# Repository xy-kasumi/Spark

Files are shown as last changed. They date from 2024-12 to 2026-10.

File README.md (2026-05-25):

# Spark

🚧 Under Construction 🚧

Spark is an OSS/OSH desktop EDM tech stack.
It'll bring the ease of 3D printing to fine metal parts.

Maybe. Someday.

This repo is mostly about software & machine CAD.

To construct a Spark machine, you need these too:
* https://github.com/xy-kasumi/Spark-corefw
  * firmware for main board (currently only supports BTT Octopus Pro)
* https://github.com/xy-kasumi/Spark-pulser
  * EDM board (PCB design & firmware)

## Directories

Directories are roughly divided into two groups.

### Build & Use

* docs: contains assembly manuals and specs
* dicer: web page that generates G-code from STL for the machine
* shell-dashboard: web page to control the machine
* shell-spooler: Go program that acts as interface between shell-dashboard & physical board
* mech: CAD files for the machine

These are necessary for building, testing, and using the machine.

### Development & Operations

* sim-wear: particle-based tool vs work simulation
  * purpose: validate & iterate on "sweep" patterns without physical experiments
* brand: contains project's visual identity such as logo

These are useful resources to further the development of the machine and/or the Spark project.

### Tips
Note: "localhost" and "127.0.0.1" are considered different origins.

When `./build.sh` or `./watch.sh` cause directory listing page to show up:
* Configure `liveServer.settings.wait` to be larger than build time. e.g. 1500 (ms)

When log output from spooler is causing refresh:
* Add `"**/logs/**"` to `liveServer.settings.ignoreFiles`.

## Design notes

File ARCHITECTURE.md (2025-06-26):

From the user's point of view, Spark stack looks like this:

```mermaid
graph LR
    Dicer --G-code--> Shell
    subgraph Machine
      Shell <--command stream--> Core
    end
```

* Dicer is a GUI that user puts 3D file & configs, and emits G-code
* Machine receives G-code via Shell, and carves out 3D physical object
  * Core is the firmware that abstracts hardware as [a serial protocol](https://github.com/xy-kasumi/Spark-corefw/blob/main/spec/protocol.md)

Machine's UI can vary:
* it can be hardware display, knobs etc
* it can be web UI

## Why not X?

### Why not Klipper?
In Klipper, Linux board runs Python to generate low-level (individual motor steps) with timestamps, and stream them to firmwares.
* Firmwares buffers low-level commands and executes them based on timestamps.

Issues
* Low-level timestamped commands (core design chocie in Klipper) will not work in EDM
  * EDM control loop needs fast (probably 100Hz+) realtime control based on sensing.
  * Python + Linux is not well-suited to handle such low-latency computation reliably for hours.
  * Monotonic timestamp is also very-baked in idea, canceling and re-ordering of commands look hard.

Good things
* Separation of UI & control

### Why not grblHAL?
grblHAL is a pretty flexible firmware for generic CNC machine.
It also provides HAL (hardware abstraction layer) for electronics, plugin-based flexible architecture.

Issues
* Too hard to change behavior of G1 for EDM-control loop
  * Lots of non-plugin exposed behavior (need to modify core code)
  * G-code & motion planning ring buffers is too baked in for a change to backtrackable data structure
* Sender GUIs assumes too much machine knoweldge from users
  * We won't be using them anyway

### Why not Marlin?
Marlin is basically everything-in-single-firmware design.

Issues
* Since machine geometry & UI will be quite different, very little can be reused from Marlin firmware.
  * Rewrite would be easier.

## Spark Architecture
Assumption is that:
* Core is very minimum; zero user I/O, no SD-card. Only command stream over UART.
* Linux single board computer (e.g. Raspberry Pi) handles every UI

Spooler provides non-realtime machine interface by:
* keep G-code cache locally
* streams G-code reliably & monitors Core even when network is offline or dashboard is gone
* spooler's knowledge of the protocol or G-code is minimum; it's basically a HTTP-accessible line-based storage

The command stream is high-level (G-code + system commands).
Core buffers hopefully more than 1 second of G-code,
to prevent occasional hiccups in Linux from causing troubles.

Final setup of Split Shell
```mermaid
graph LR
  subgraph Host
    Dashboard["Dashboard in browser"]
  end
  subgraph Machine
    subgraph Single Board Computer
      Server["HTTP Server"]
      Static["Dashboard Static Files"]
      Spooler
      Server--reads-->Static
      Server--proxies-->Spooler
      PhysUI["Physical UI"] -->Spooler
    end
    subgraph Electronics
      Core["Core Firmware"]
    end
    Spooler<--command stream-->Core
  end
  Dashboard--->Server
```

By having "Physical UI" program which interfaces with buttons, displays, speakers etc,
it's very easy to have on-device rich UI if wanted.

Split shell configuration allows same dashboard & spooler to be used in host environment,
offering rich & flexible dashboard while developing hardware & electronics.
```mermaid
graph LR
  subgraph Host
    Dashboard --> Spooler
  end
  subgraph Machine
    subgraph Electronics
      Core["Core Firmware"]
    end
  end
  Spooler<--command stream-->Core
```

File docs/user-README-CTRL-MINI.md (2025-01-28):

# CTRL-MINI (r0) User Manual

This doc is for users of the CTRL-MINI board.
It serves as both a datasheet and an operating manual.

## Overview

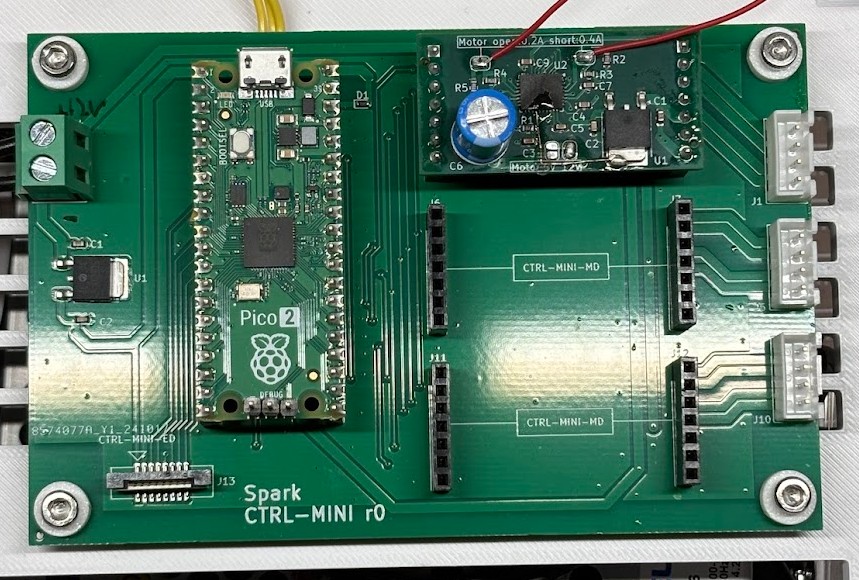
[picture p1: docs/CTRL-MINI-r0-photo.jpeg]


CTRL-MINI is the main board of a Spark machine.
In the current prototype phase, it serves as an experimental hub.
Major revisions are expected in future iterations.

It features the following functionality:
- Terminal-like interface for human operator via RasPi probe
- 3-axis bipolar stepper motor driver with swappable child boards (CTRL-MINI-MD)
  - 12V, 0.4-ish A per phase
  - Features Trinamic TMC2130 driver with 1/256 microstepping capability
- Connectivity to CTRL-MINI-ED board

Note: The architectural relationship between CTRL-MINI and CTRL-MINI-ED (whether as a sub-component or separate board) is TBD. This document treats it as a separate board.

### Power Supply

Screw terminal on the left side:
- Input: 12VDC
- Current: 2A minimum recommended
  - 1A minimum if using reduced motor current
  - Higher current ratings are OK

### Connections

Right edge: Motors
- 3x XH connectors
  - Pin configuration (top to bottom):
    1: A1
    2: A2
    3: B1
    4: B2

Bottom edge: CTRL-MINI-ED connection
- Upright connector for FFC (Flat Flexible Cable)
  - Type-A, pitch 1mm, 8 pins
  - Terminal thickness: 0.3mm

Top edge: RasPi Probe (Serial Communication)
- QI female 3-pin connector
  1: TX
  2: RX
  3: GND

### Mechanical
Reference orientation: "Spark" text on board facing up

**General**
* Outer dimensions: 115mm (width) x 75mm (height) x 25mm (depth)
* Mass: to-be-measured

**Mounting**
Board dimensions: 115mm (width) x 75mm (height)
- 4x mounting holes:
  - Coordinates: (5mm, 5mm), (5mm, 70mm), (110mm, 5mm), (110mm, 70mm)
  - Hole diameter: 3.3mm
  - Clearance for screw head/spacer: 8mm diameter
  - Mounting areas are electrically isolated

## Terminal Interface

Connect the RasPi probe's serial port to the 3-pin QI connector.
Use any terminal emulator software on the host computer.

Required configuration:
- Baud rate: 115200

Recommended configuration:
- Line ending: CR (for both TX/RX)
- Local echo: ON

Interface behavior:
- Commands are single-line only (no multi-line support)
- Input control:
  - `Ctrl-C` or `Ctrl-K`: Cancel current command
  - Other control keys are not supported (backspace, arrows, delete)

### High-Level Commands

#### `status`
* **Description:** Prints the status of the system.

#### `edparam <duration_us> <duty> <current_ma>`
* **Description:** Configures pulse duration, duty factor, current. Will affect `drill` command.
* **Parameters:**
  * `duration_us`: integer, pulse duration in microseconds (range: 5 to 10000)
  * `duty`: integer, max duty ratio in percent (range: 1 to 50)
  * `current_ma`: integer, current in mA (range: 100 to 8000). Will be rounded down to possible value.

#### `move <board_ix> <distance>`
* **Description:** Moves the specified board by a given distance (in millimeters).
* **Parameters:**
  * `board_ix`: 0, 1, or 2
  * `distance`: float (in mm)

#### `find <board_ix> <distance>`
* **Description:** Moves up to a specified distance or until the electrode touches the work.  
  Uses a hot electrode scan and may cause slight damage to the work.
* **Important:** Must be issued after `edon`.
* **Parameters:**
  * `board_ix`: 0, 1, or 2
  * `distance`: float (in mm)

#### `drill <board_ix> <distance>`
* **Description:** Drills by a specified distance. Actual drill depth may be less due to tool wear.
* **Important:** Must be issued after `edon`.
* **Parameters:**
  * `board_ix`: 0, 1, or 2
  * `distance`: float (in mm)

### Motor Driver (MD) Commands

#### `step <board_ix> <step> <wait>`
* **Description:** Steps one motor in one direction at a constant speed.
* **Parameters:**
  * `board_ix`: 0, 1, or 2
  * `step`: integer (negative or positive), in microsteps
  * `wait`: integer, wait time after each microstep, in microseconds

#### `home <board_ix> <direction> <timeout_ms>`
* **Description:** Moves the motor to the home position (where it stalls).
* **Parameters:**
  * `board_ix`: 0, 1, or 2
  * `direction`: `-` or `+`
  * `timeout_ms`: integer, timeout in milliseconds

#### `regread <board_id> <addr>`
* **Description:** Reads a register from peripheral boards.
* **Parameters:**
  * `board_id`: 0, 1, 2, E
  * `addr`: hexadecimal value from `00` to `7f`

### Low-Level Commands

#### `regwrite <board_id> <addr> <data>`
* **Description:** Writes to a register on the peripheral boards.
* **Parameters:**
  * `board_id`: 0, 1, 2, E
  * `addr`: hexadecimal value from `00` to `7f`
  * `data`: hexadecimal, 1-byte for E, 4-byte for 0,1,2
* **Examples:**
  * `regwrite E 02 01`
  * `regwrite 0 10 1f10`

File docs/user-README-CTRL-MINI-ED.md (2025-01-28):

# CTRL-MINI-ED (r1) User Manual

This doc is for users of the CTRL-MINI-ED board.
It basically serves as both a datasheet and an operating manual.

## ⚠️ Safety warning ⚠️
Improper use of CTRL-MINI-ED may cause death, fire, or damage to nearby devices.

## Overview

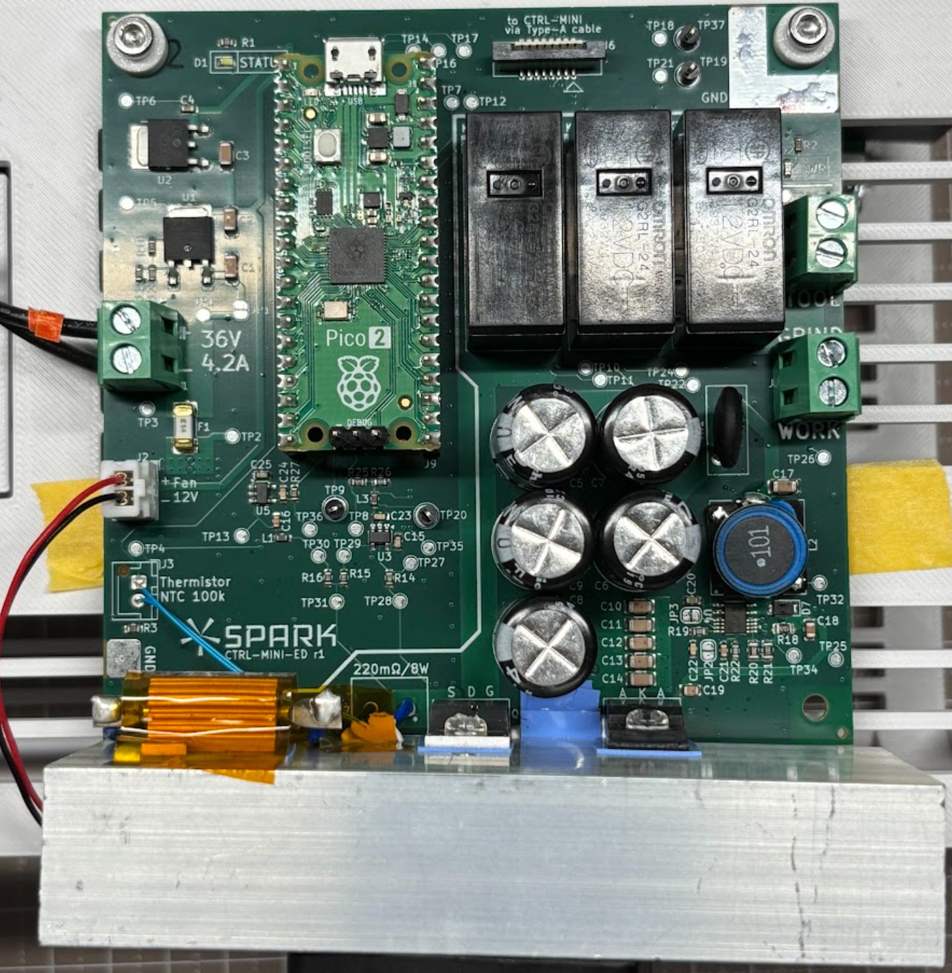
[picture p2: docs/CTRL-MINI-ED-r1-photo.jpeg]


CTRL-MINI-ED is an EDM discharge board, controllable via digital IOs and I2C.

* Max pulse current: 8A (at duty factor=50%)
* Open voltage: 100V
* 5 dynamic polarity configurations
  * (Tool+, Work-), (Tool-, Work+)
  * (Tool+, Grinder-), (Tool-, Grinder+)
  * Disconnected
* Single-pulse discharge timing control, and pulse current detection via GATE/DETECT digital IOs
* Pulse current, detection threshold, polarity control, temperature monitoring via I2C

### Power Supply
Screw terminal on the left side
* DC 36V, 4.2A minimum

If the power supply is below 4.2 A, the microcontroller might reset accidentally at high-power setting.
Above 4.2 A should be fine, but too much output (e.g. 10 A) will increase the damage in case of firmware bug.

### Indicators

* Status (white) LED: ON if OK. Blinks if error. OFF means hardware or firmware failure.
* Power (red) LED: Indicates that electrodes are potentially energized. Blinks if error.

Even after sudden power failure, electrodes should be in high-impedance state if the Power (red) LED is OFF.
When the board enters an error state, the only way to recover is through a power reset.

### Connections

Control Connector:
* Upright connector for FFC (Flat Flexible Cable)
  * Type-A, pitch 1mm, 8 pins, terminal thickness 0.3mm

Electrodes:
* three screw-terminals on the right side ("Wire", "Grind", "Tool" marking on the PCB)

### Mechanical & Thermal
* Listed values are board with heatsink and fan
* "height", "width" etc. is based on "Spark" logo on the board

**General**
* Outer dimensions: 135mm (width) x 105mm (height) x 50mm (depth)
* Mass: 240g

**Mounting**
Board dimensions: 100mm (width) x 100mm (height)
* 4 mounting holes at (5mm, 5mm), (5mm, 95mm), (95mm, 5mm), (95mm, 95mm)
* Hole dia: 3.3mm, dia available for screw head, spacer etc: 6.5mm
  * available area is either isolated or GND

**Thermal**
* Max heat generation: 75W
  * Ensure adequate airflow at the bottom of the PCB for proper fan operation.

## Controller Interface

CTRL-MINI-ED is designed to be safe (de-energized) to be turned on with "Control Connector" disconnected.

### Physical layer
"Control Connector" pinout (at **host-side**. See note.):
1. Don't Connect
2. GND
3. Don't Connect
4. I2C SDA
5. Don't Connect
6. I2C SCL
7. GATE
8. DETECT

Note: Type-A (terminals on same-side) means cross-cable. Thus, pinout at host and ED board is flipped.

* I2C SDA/SCL: 3.3V I/O. Standard Mode (~100kHz). Pulled-up in ED board.
* GATE: 3.3V digital input
* DETECT: 3.3V digital output

### I2C layer

* Device Address: 0x3B
* Speed: Standard Mode (~100kHz clock)

Within the device, there are registers with 1-byte address and 1-byte data.
Write command writes to a single register, Read command read from a single register.

They involve internal pointer. They don't auto-increment.

**Write**
* M: START
* M: Device Addr (7bit; 0x3B) + Write flag (1bit; 0)
* S: ACK
* M: Register Addr (8bit)
* S: ACK
* M: Data (8bit)
* S: ACK
* M: STOP

This also sets the internal pointer to Register Addr.

**Read**
(write pointer)
* M: START
* M: Device Addr (7bit; 0x3B) + Write flag (1bit; 1)
* S: ACK
* M: Register Addr (8bit)
* S: ACK
(read data from pointer)
* M: Repeated START
* M: Device Addr (7bit; 0x3B) + Read flag (1bit; 1)
* S: Data (8bit)
* M: NACK
* M: STOP

(M: master, S: slave)

### Logical layer

### GATE/DETECT
The host can initiate a single pulse by setting GATE to HIGH.
If the discharge condition is good, discharge will happen after a random Tig (ignition time).
Tig is inherently random, but typically ranges from 10μs to 500μs, and becomes shorter if the gap is narrower.

If DETECT becomes HIGH very quickly (within 5μs), it is highly likely that the discharge gap is short-circuited.
In that case, the host should set GATE to LOW immediately.

Generally, GATE can be thought of as directly driving the MOSFET gate. However, for safety and device longevity,
actual driving can be suppressed. See the "Timing wrt. GATE/DETECT" section for details.

DETECT becomes HIGH whenever discharge current is detected.
The host is responsible for monitoring DETECT and setting GATE to LOW after the desired pulse duration time.
The current detection threshold is auto-set to 25% of pulse current by the ED board.

When POLARITY or PULSE_CURRENT is updated, DETECT can become LOW even when actual discharge
current is still flowing.



There is a constraint for combinations of pulse time, pulse current, and duty factor.
See the "Pulse Shaping" section for details.

Safety note: electrodes are **energized even when GATE is LOW**

Setting GATE to LOW merely means turning down the current close to 0.
However, open voltage of 100V is still present on the electrodes,
and the driver will allow more than 10mA current to flow, which is enough to kill you.

To actually turn them off, you need to set POLARITY to OFF.

### Control Registers
|Address| Register | Access | Resets to | Description |
|---|---|---|---|---|
| 0x01  | POLARITY | RW | 0 | 0: OFF, 1~4: energize with certain polarity. |
| 0x02  | PULSE_CURRENT | RW | 10 | pulse current in 100mA step. 1 (100mA) ~ 80 (8A) is allowed. |
| 0x03  | TEMPERATURE | R | N/A | current heatsink temperature in ℃. 80 means 80℃. 255 means temp reading is unavailable due to severe issue. |

Register access:
* RW: read-write
* R: read-only

Invalid value writes are:
* set to safe default such as OFF (e.g. POLARITY)
* set to nearest valid value (e.g. PULSE_CURRENT)
* ignored for read-only or unused registers (e.g. TEMPERATURE)

#### Timing wrt. GATE/DETECT

Writes to POLARITY & PULSE_CURRENT immediately updates the register.
However, when register is changed during GATE is HIGH,
* change will take effect from the next pulse (once GATE become LOW)
* actual EDM driver will be suppressed for 1ms (PULSE_CURRENT change) and 20ms (POLARITY change)
  * this will lead to very large observed DETECT from the host

As an exception to the delay above, setting POLARITY to OFF immediately shutdown EDM driver.

#### POLARITY

* 0: OFF
* 1: TPWN (Tool+, Work-)
* 2: TNWP (Tool-, Work+)
* 3: TPGN (Tool+, Grinder-)
* 4: TNGP (Tool-, Grinder+)

### Pulse Shaping

Pulse current is limited due to the internal capacitor bank.
* Always: Ip <= 8A (enforced by register)
* When Ip >= 4A: Tp <= 8mC / Ip
  * Tp (max) = 1ms @ Ip = 8A
  * Tp (max) = 1.3ms @ Ip = 6A
* When Ip >= 4A: Ip * DF <= 4A
  * DF (max) = 50% @ Ip = 8A

If DF or pulse duration exceeds these values, discharge current will dwindle to 4A (power supply current) or cause an abrupt voltage drop.

The ED board driver is optimized for EDM. It uses a combination of:
* 100V low-capacity "ignition supply"
* 36V high-capacity "discharge supply"

This is possible because the gap voltage, once ignited, becomes about 20V (up to ~30V, depending on conditions).
This dual supply driver is power-efficient but produces unexpected behavior when connected to non-discharging loads.

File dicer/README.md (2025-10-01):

## Running Dicer
Run `make`. This will generate `dist/`. First-time will be slow, as it will download Emscripten SDK & Manifold libarries.

Serve the `dicer/` or `spark/`. Open `dicer/dist/index.html` in browser.

## Development
Run `make typecheck` to check types correctness w/o touching `dist/`.
Need to run `make` whenver source files are edited.

Run `make clean` to remove built files.

Run `make clean-all` to remove SDKs and libraries too.

### TypeScript Definitions
- `types/qunit.d.ts` - Original QUnit definitions from DefinitelyTyped
- `types/qunit-extensions-v2.d.ts` - Missing QUnit methods from v2
- `types/vendor.d.ts` - Custom .d.ts maintained by us. Aim for max benefit/cost, rather than completeness.

## Internals & Definitions
All coordinate systems are right-handed.

* "setup coordinates"
  * what users see in dicer.
  * Z+ is up. XY-center is stock profile center.
    * stock is always extrusion of a an XY-aligned profile in Z direction.
    * e.g. cylinder (circle in XY extruded in Z), bar (rectangle in XY extruded in Z)
  * Target shape resides in Z+ half-space, "resting" on XY-plane.
* "work coodinates"
  * same as [G55 work coordinate](https://github.com/xy-kasumi/Spark-corefw/blob/main/spec/gcode.md#g55-use-work-coordinate-system)
  * origin is chuck base center
  * stock resides in X- direction
    * profile is mostly YZ-center aligned, but might have offset depending on chuck types

Dicer computes paths in setup coordinates, and then convert them to work coordinates when emitting G-code.

Setup coordinates and work coordinates shares Y+ axis direction.

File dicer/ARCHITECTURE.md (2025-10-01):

# Core Assumptions / Hypotheses
By reading this doc, you'll know how much effort you should use when touching various parts of the code.

This document outlines the foundational truths (axioms), important assumptions, and smaller hypotheses that underpin Dicer.
Each has different implications for how "defensive" or "throwaway" we can be when writing code.

* Axioms: Bedrock truths; if wrong, requires complete rewrite. (30 days)
  * Baked into architecture. No defensive coding needed.
* Assumptions: Important but less absolute; affects ~10% of code. (3 days)
  * Be somewhat defensive - these might change later
* Hypotheses: Small details; affects ~1% of code. (a few hours)
  * Safe to discard or rewrite

Current projection: Dicer needs 30 days to reconstruct from scratch with correct assumptions.
This corresponds to 3K~30K lines of code+doc.

## Axioms
* Dicer converts 3D mesh into G-code
* Dicer provides interactive configuration
* Good G-code generation is the main value of Dicer; thus its logic update will never cease
  * "Good G-code": Aligns with Spark machine's goal (versatile, accurate, robust)
  * -> Path generation logic is continuously running "module" with GUI hooks to allow quick visualization & iteration, instead of test-hardened pure geometry library
* EWR (electrode wear ratio) is bounded, and its value can be user-measurable
  * -> This is the premise of path generation logic. Unbounded EWR means machine needs continuous sensing, completely destroying machine design itself.
* Dicing completes within "non-coffee-break" time to keep interactive configuration meaningful
  * Target: 10 seconds typical, 30 seconds max for complex cases
* Dicer runs on Web browser environment
* Dicer does not depend on external servers

## Assumptions
* Dicer consumes STL file as 3D mesh
* Triangle mesh representation is "better" than other representations (voxel, CSG, NURBS)
  * "better": Amount of effort to achieve correctness is lower while being fast enough

## Hypotheses
* Not documented (cost of separate documentation outweighs cost of re-writing code)
* e.g. SDF should be passed around as serializable Shape object, instead of a function

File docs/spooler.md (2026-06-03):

# Spooler

Spooler manages the [core firmware](https://github.com/xy-kasumi/Spark-corefw/) over serial comm.
It provides
* Command multiplexing & long-running job streaming, via HTTP API
* Text log for later consumption

Spooler's knowledge:
* knows
  * line-based comm (and `; ...` comment stripping)
  * about p-state format
  * queue control (`?queue`, `queue`)
  * cancellation (`!`)
* does not know
  * G-code, Commands (e.g. what "G1", "set", "?pos" means), p-state contents (other than queue)

Terminology
* `up`: comm towards the user (core -> spooler -> UI -> user). `down` is the opposite.
* `init file`: text file that is persisted across reboot, useful for initializing the core. Its lines are queued as commands at the start of each session.
* `session`: a contiguous span during which the device is alive (responding to `?queue`).

## HTTP API

Spooler uses HTTP as RPC.
All API is POST, both request & response are `application/json`.

It sticks to just 3 types of status codes.
* 200 OK: Request is processed succesfully, response is JSON.
* 400 Bad Request: Returned for non-comforming (syntax or semantics) request. Response is human-readable error text.
* 500 Internal Server Error: Request seemed ok, but somehow processing failed. Response is human-readable error text.

### POST /write-line

Send a line.

**Request Schema**

```yaml
properties:
  line: {type: string}
optionalProperties:
  high_prio: {type: bool}
```
* `line`: a valid payload (should not contain newline)
* `high_prio`:
  * if `true`, the payload is sent immediately regardless of job
  * if `false`, it is queued as a command and fails while a job is `WAITING`/`RUNNING`.

**Response Schema**

```yaml
properties:
  ok: {type: bool}
  time: {type: float64}
```
* `ok`: command was enqueued. `false` also indicates the device is currently dead.
* `time`: time of spooler enqueue (timestamp)

**Examples**

Request:
```json
{
  "line": "G1 X10 Y20",
  "high_prio": false
}
```

Response:
```json
{
  "ok": true,
  "time": 1735689600.123
}
```

### POST /get-ps

Get latest p-states of specified tag.

**Request Schema**
```yaml
properties:
  tag: {type: string}
optionalProperties:
  count: {type: int}
```

* `tag`: P-state tag (e.g. "queue", "stat", "init")
* `count`: Max number of p-states to return (must be > 0). 1 if omitted.

**Response Schema**
```yaml
properties:
  pstates:
    elements:
      properties:
        time: {type: number}
        kv: {values: {}}
```

* `pstates`: in latest-first order.
* `time`: timestamp of the p-state reception
* `kv`: flattened representation of p-state (i.e. key can contain ".")

**Example**
Request
```json
{
  "tag": "pos",
  "count": 2
}
```

Response
```json
{
  "pstates": [
    {
      "time": 1735689600,
      "kv": {
        "m.x": 1
      }
    },
    {
      "time": 1735689500,
      "kv": {
        "m.x": 2
      }
    }
  ]
}
```

### POST /status

Get spooler status summary.

**Request Type**

```json
{}
```

**Response Schema**

```yaml
properties:
  time: {type: float64}
  device_alive: {type: bool}
  busy: {type: bool}
  num_pending_commands: {type: int}
optionalProperties:
  running_job: {type: string}
```

* `time`: spooler timestamp of this status
* `device_alive`: true iff the spooler currently believes the device is responsive
  (responding to `?queue`).
* `busy`: some commands are pending to execute (or being executed). High-prio writes do not count as busy.
* `num_pending_commands`: number of commands (either directly or via job)
  * includes commands in core queue
* `running_job`: job_id if a job is running

**Examples**

Request:
```json
{}
```

Response:
```json
{
  "time": 1735689600.123,
  "device_alive": true,
  "busy": true,
  "num_pending_commands": 37
}
```

### POST /cancel

Cancel everything through the stack, including:
* currently running command in core (if device is alive)
* command queue in core (if device is alive)
* command queue in spooler
* waiting / running job in spooler

**Request Type**

```typescript
{}
```

**Response Type**

```typescript
{}
```

### POST /set-init

Set content of init lines. The content will be persisted as a file across spooler reboot.

**Request Type**

```typescript
{
  lines: Array<string>
}
```

**Response Type**

```typescript
{}
```

**Examples**

Request:
```json
{
  "content": ["set cs.g.pos.x 1", "set cs.g.pos.x 2"]
}
```

### POST /get-init

Get current init lines. Empty if not configured or not found.

**Request Type**

```typescript
{}
```

**Response Type**

```typescript
{
  lines: Array<string>
}
```

**Examples**

Request:
```json
{
  "content": ["set cs.g.pos.x 1", "set cs.g.pos.x 2"]
}
```

### POST /add-job

Add a "job", which is a command-list + polls.
Add only succeeds if all existing jobs are ended (`CANCELED` or `COMPLETED`).

Job only starts executing when command queue of both spooler and core become is fully empty.
Job completes when all `commands` are sent and core queue become fully empty.

**Request Schema**
```yaml
properties:
  commands:
    elements: {type: string}
  polls:
    values: {type: float32}
```

* `commands`: list of commands to be executed
* `polls`: list of commands to be periodically sent (interval in sec)

Caller needs to be careful to only send queue-able `commands` and immediate-execute `polls`
to avoid weird execution order or queue overload.

**Response Schema**
```yaml
properties:
  ok: {type: bool}
optionalProperties:
  job_id: {type: string}
```

* `ok`: job was accepted. `false` also indicates the device is currently dead.
* `job_id`: Unique id describing the job in the spooler. Undef if !ok.

**Examples**
Request
```json
{
  "commands": [
    "set m.x 3",
    "G0 X10 Y10",
    ...
  ],
  "polls": {
    "?pos": 1,
    "?edm": 0.5
  }
}
```

Response
```json
{
  "ok": true,
  "job_id": "A3zF"
}
```

### POST /list-jobs

List all added jobs.

**Request**
```json
{}
```

**Response Schema**
```yaml
properties:
  jobs:
    elements:
      properties:
        job_id: {type: string}
        status:
          enum: [WAITING, RUNNING, COMPLETED, CANCELED, FAILED]
        time_added: {type: float64}
      optionalProperties:
        time_started: {type: float64}
        time_ended: {type: float64}
```

* `status`: Current status of the job
  * `WAITING`: added but not started
  * `RUNNING`: job is currently being executed
  * `COMPLETED`: job was executed succesfully (all commands consumed)
  * `CANCELED`: job was cancled without becoming completed
  * `FAILED`: job was terminated because of device death or other critical errors
* `time_added`, `time_started`, `time_ended`: timestamps
  * `time_started`: undef for `WAITING`
  * `time_ended`: undef for `WAITING` or `RUNNING`

### POST /query-ts

Query time-series data from p-state.

**Request Schema**
```yaml
properties:
  start: {type: float64}
  end: {type: float64}
  step: {type: float64}
  query:
    elements: {type: string}
```

* `start`, `end`: timestamps to specify time range, inclusive. End >= start.
* `step`: resolution in seconds (> 0)
* `query`: p-state tags and keys to query in `<tag>.<keys>` format

`start`, `end`, `step` determines query timestamps like
* start + step * 0, start + step * 1, ...
  * this continues until end. The last element can be smaller than, or same as end.
  * in valid request, this will always contain at least one element (start)

For each timestamp T, latest original data point in window [T-step, T] is returned.
/query-ts will never re-sample the data.

When step is smaller than sampling rate of original data, response will contain lots of nulls inbetween.

**Response Schema**
```yaml
properties:
  times:
    elements: {type: float64}
  values:
    values: {}
```

* `times`: sequence of Unix timestamps, as calculated by `start`, `end`, `step`.
* `values`: sequence of data. null if data is missing.

All the arrays (`times`, and each element of `values`) has same length.

**Examples**
Request
```json
{
  "start": 1735689600,
  "end": 1735690600,
  "step": 10,
  "query": ["pos.x", "edm.open"]
}
```

Response
```json
{
  "times": [
    1735689600,
    1735689610,
    ...
    1735690600
  ],
  "values": {
    "pos.sys": ["machine", "machine", "work", ...],
    "edm.open": [0.1, 0.2, ...]
  }
}
```

### Appendix: Timestamps
All timestamps use Unix time in seconds.
They should have at least millisecond precision.

Note that leap seconds might end up elongating "1 second" for a day (smearing),
or time can reverse for that duration.

Implementation should not crash when encountering such timestamps,
but OK to lose data for that period.

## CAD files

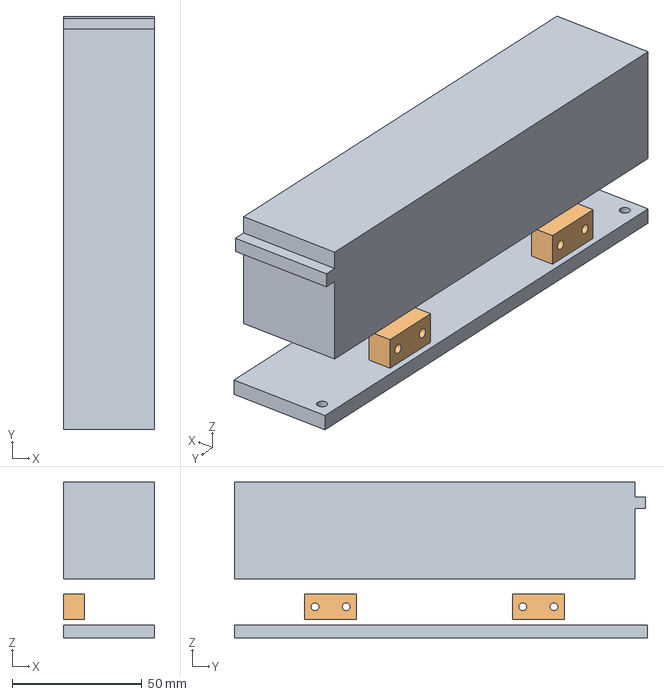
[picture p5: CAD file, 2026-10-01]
mech-wg3/mm-xz/mm-xstage-assy.FCStd
35.0 x 159.0 x 60.0 mm
beltdrive-body
pack-body x 2

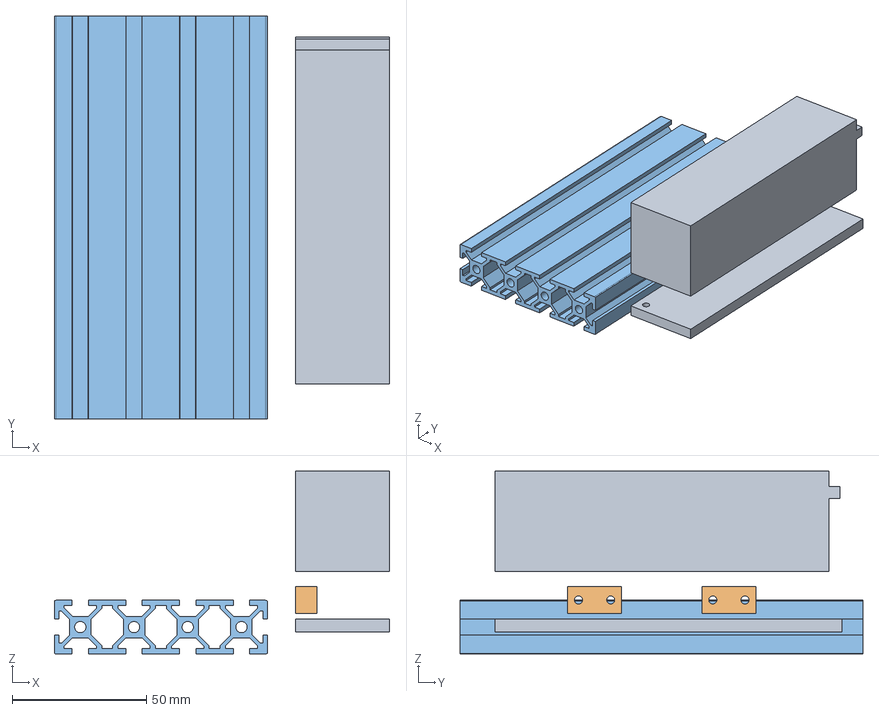
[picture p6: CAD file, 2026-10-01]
mech-wg3/mm-y/mm-y-assy.FCStd
124.7 x 150.0 x 68.1 mm
beltdrive-body
pack-body x 2
HFS5-2081

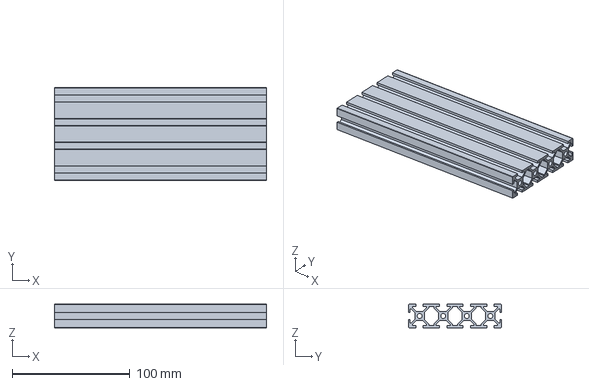
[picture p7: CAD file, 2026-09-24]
mech-wg3/mm/mm-assy.FCStd
180.0 x 79.2 x 20.0 mm

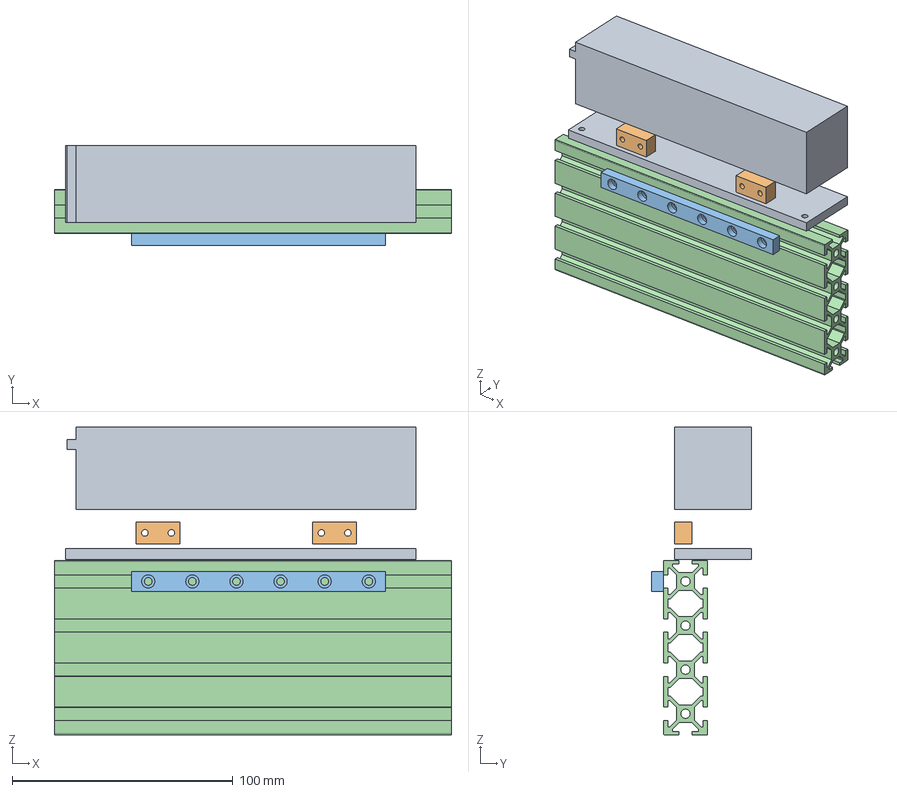
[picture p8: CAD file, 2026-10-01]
mech-wg3/mm-xz/mm-x-assy.FCStd
180.0 x 45.5 x 139.6 mm
beltdrive-body001
pack-body001 x 2
mock-SSE10-rail
HFS5-2080

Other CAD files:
mech-wg3/machine-assy.FCStd
mech-wg3/work-spindle/chuck-assy.FCStd
mech-wg3/cbox-assy.FCStd
mech-wg3/fluidics/converter-assy.FCStd
mech-wg3/tool-spindle/z-coupler-2-assy.FCStd
mech-wg3/base-assy.FCStd
mech-wg3/beltdrive/beltdrive-assy.FCStd
mech-wg3/grinder/wirepreguide-assy.FCStd
mech-wg3/frame-assy.FCStd
mech-wg3/grinder/puller-assy.FCStd
mech-wg3/tool-spindle/assy-scissor.FCStd
mech-wg3/grinder/bracket-clamp-assy.FCStd
mech-wg3/work-spindle/work-spindle-assy.FCStd
mech-wg3/grinder/idler-assy.FCStd
dicer/assets/models/GT2_pulley.stl
dicer/assets/models/M3x10.stl
dicer/assets/models/bearing_inner.stl
dicer/assets/models/bearing_outer.stl
dicer/assets/models/benchy_25p.stl
dicer/assets/models/collet.stl
dicer/assets/models/cube_lattice.stl
dicer/assets/models/flush_end.stl
dicer/assets/models/fractal_step.stl
dicer/assets/models/helical_gear.stl
dicer/assets/models/idler.stl
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

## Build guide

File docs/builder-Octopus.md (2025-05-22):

# Using Octopus Pro board for main controller

This doc explain wiring & firmware setup for using Octopus Pro board.

Necessary hardware:
* [BIGTREE TECH Octopus Pro (H273, V1.1) Board](https://biqu.equipment/products/bigtreetech-octopus-pro-v1-0-chip-f446) x1
  * MCU: STM32H723
  * [user guide](https://github.com/bigtreetech/BIGTREETECH-OCTOPUS-Pro/blob/master/BTT_Octopus_pro_EN.pdf)
  * [circuit schematics](https://github.com/bigtreetech/BIGTREETECH-OCTOPUS-Pro/blob/master/Hardware/BIGTREETECH%20Octopus%20Pro%20V1.1-sch.pdf)
  * [pins](https://github.com/bigtreetech/BIGTREETECH-OCTOPUS-Pro/blob/master/Hardware/BIGTREETECH%20Octopus%20Pro%20-%20PIN.pdf)
* TMC2209 stepper drivers x7

## Wiring

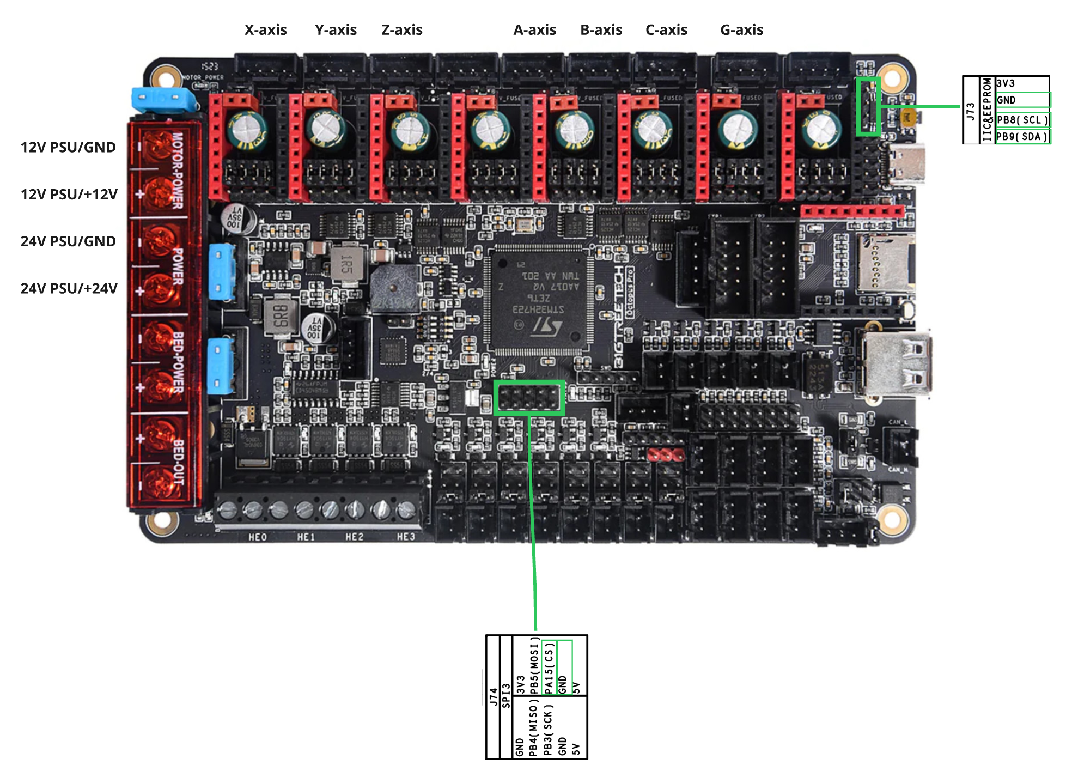
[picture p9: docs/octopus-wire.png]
wiring photo


Power Input

* MOTOR_POWER: +12V PSU
* MB_POWER: +24V PSU
* BED_POWER: N/C

Disable USB-power and use PSU power by removing J68 jumper.

Stepper Motor

* Motor DIP
  * Comm mode: Set all 8 to "UART Mode"
  * Power: Use "Motor Power"
* Motor board: Insert TMC2209 boards (x7) in motor 0~6.
* Motor 0,1,2,3,4,5: X,Y,Z,A,B,C respectively
* Motor 6: Wire feeder

Other DIP

* MCU Power Jumper: Remove (Use MB_POWER insterad of USB power)

PULSER Connection
* SCL, SDA (J73, 3.3V, shared with an EEPROM. Pulled-up by 4.7k)
  * SCL: PB8, SDA: PB9
  * J73: 3.3V, GND, SCL, SDA
* GATE (J74-pin6, 3.3V)
  * SPI3_NSS: PA15
  * J74: pin6: SPI3_NSS, pin8: GND

## Firmware build environment
You need VSCode with PlatformIO extension.

1. Clone https://github.com/xy-kasumi/Spark-grblHAL and open the top-level folder in VSCode.
2. Click PlatformIO icon in the left sidebar. In "Project Tasks", you'll find "btt_octopus_pro_h723_tmc2209_spark" target.
3. Click "General > Build" to compile, "General > Upload" to write the firmware via USB.
    * When you modify platform.ini, it takes a few seconds for the menu to refresh.

## Firmware flashing

Setup
* Connect the board to PC via USB-C cable (for firmware writing via DFU)
* Prepare serial connection between the board and the host
    * Connect the board to RasPi Probe (or any other serial probe) TX2(PD5): board->host
    * Open serial console (e.g. TeraTerm) and set baudrate to 115200.

1. Put jumper to J75 (BOOT0) while the board is OFF.
2. Turn on the power and connect to PC via USB-C.
3. Run "Upload" in PlatformIO. Comfirm the operation status ended with "SUCCESS".
4. Power off the board and remove the jumper from J75 (BOOT0).
5. Power on the board. After about 5 seconds, you should see a few lines starting with `GrblHAL 1.1f ['$' or '$HELP' for help]` in the serial console.

See errors.c for error codes.

Quick test
```
$14=7 (disable "Start", "Hold", "Reset" by flipping them)
$X (unlock alarms)
$J=G91 X50 F100 (move X motor for 30 seconds)
```

### TBD

HE0~3 (24V = MB_POWER)
* Has flywheel diodes
  * can be used for pump control

## Firmware preparation

## Firmware update

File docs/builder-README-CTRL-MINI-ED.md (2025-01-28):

# CTRL-MINI-ED (r1) Builder Manual

This doc is for people who want to build, modify, test ED board.
Current it's written for r1 (r0 didn't have any such doc).

## Assembly

You'll need the following
* PCBA-ed board
* heatsink
* 12V fan (2pin, XH connector)
* thermal sheet with electric isolation
* plastic M3 screw x2
* 220mΩ resistor & wire
* NTC 100kΩ free-hanging thermistor

Using these parts, you need to attach everything in one thermal block.

The termistor should be secured especially firmly,
because over-temperature protection depends on the thermistor reading.

The diode and the transistor's back plate may or may not be High-V.
Better to treat them as High-V, and apply isolation.
That way touching heatsink won't electrocute you.

## Test procedures

(Before tests)
Install external parts: current sense resistor, thermistor, heatsink, fan, Pico 2.

You should execute test groups sequentially. (i.e. execute _noconn only after _nofw is PASS)
Some tests don't make sense, or even dangerous, without preceding test groups.

### _nofw (No firmware)
Connect to 36V supply.

Tests:
* _nofw_led: LEDs = OFF
* _nofw_smoke: No smoke, max temp in thermography < 70℃ (Tamb<30℃) after 1 min
* _nofw_fan: fan = ON
* _nofw_pow: Power line voltages are nominal for:
  * _nofw_pow_uc: 5±0.5V (TP6), 3.3±0.5V (TP7)
  * _nofw_pow_dchg: 12±1V (TP5), 36±2V (TP26), 100±3V (TP25)
* _nofw_curr: Board current draw = 0.08±0.01A
* _nofw_out: GRINDER, WORK, TOOL = High-Z

### _nohost (No host connection)
Install firmware.

Tests:
* _nohost_led: Status LED = ON, Power LED = OFF
* _nohost_smoke: No smoke, max temp in thermography < 70℃ (Tamb<30℃) after 1 min

### _host (Host connection)
Connect to host. Host must be able to read/write registers.

Tests:
* _host_temp: Read TEMPERATURE. Must be within 5 degrees C of Tamb.
* _host_pol1: Write 1 to POLARITY. Relay switch sound, PWR(red)=ON, T=100V, W=0V, G=High-Z
* _host_pol2: Write 2 to POLARITY. Relay switch sound, PWR(red)=ON, T=0V, W=100V, G=High-Z
* _host_pol3: Write 3 to POLARITY. Relay switch sound, PWR(red)=ON, T=100V, W=High-Z, G=0V
* _host_pol4: Write 4 to POLARITY. Relay switch sound, PWR(red)=ON, T=0V, W=0V, G=100V
* _host_pol0: Write 0 to POLARITY. Relay switch sound, PWR(red)=OFF, T=High-Z, W=High-Z, G=High-Z

### _res (Resitive load)
Preparation
* Connect to host. Host must be able to read/write registers.
* Connect 12Ω load between Tool & Work.

Tests:
* _res_

100mA, 200mA
4A, 4.1A
7.9A, 8A

## Calibrations and other tweaks

## Real world measurements
Measurement procedures during actual EDM.

### _pulse
Prepare CTRL-MINI-ED, host controller, work & tool in operation fluid.

Trigger:
  M_GATE
  CURR_GATE
  CURR_DETECT
Current:
Voltage:

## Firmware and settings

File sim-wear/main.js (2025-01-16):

import * as THREE from 'three';
import { GUI } from 'three/addons/libs/lil-gui.module.min.js';
import { OrbitControls } from 'three/addons/controls/OrbitControls.js';
import { RadixSortKernel} from 'radix-sort';

// Units
// distance: mm
// time: sec

// Represents connected metal.
class Shape {
    // Specify solid in world coordinates. shape is generated in local coordinates, then rotated, and then translated by offset.
    // Shape is generally centered at the origin of local coordinates, and "special" axis pointing in Z.
    // [in] shapeType: "box" | "cylinder"
    // [in] shapeParams
    //   shapeType == "box": { size: THREE.Vector3 }
    //   shapeType == "cylinder": { diameter, height } (diamter: XY, height: Z length)
    constructor(shapeType, shapeParams) {
        this.shapeType = shapeType;
        this.shapeParams = shapeParams;
        if (shapeType === "box") {
            this.sizeLocal = shapeParams.size;
        } else if (shapeType === "cylinder") {
            this.sizeLocal = new THREE.Vector3(shapeParams.diameter, shapeParams.diameter, shapeParams.height);
        } else {
            throw new Error(`Unknown shape type: ${shapeType}`);
        }
    }
}

class GpuKernels {
    constructor(device) {
        this.device = device;
        this.#compileInit();
        this.#compileApplyCylinder();
        this.#compileApplyTransform();
        this.#compileComputeAABB();
        this.#compileGatherActive();
        this.#compileComputeCellIx();
        this.#compileIndexGrouping();
        this.#compileComputeMins();
        this.#compileRadixPadding();
        this.#compileComputeNormal();
    }

    // Create buffer for compute.
    // Supports: read/write from shader, bulk-copy from/to other buffer, very slow write from CPU
    // Does not support: bulk read to CPU
    createBuffer(size) {
        return this.device.createBuffer({
            size: size,
            usage: GPUBufferUsage.STORAGE | GPUBufferUsage.COPY_SRC | GPUBufferUsage.COPY_DST,
        });
    }

    // Create uniform buffer & initialize with initFn.
    // [in] size: number, bytes
    // initFn: (ptr: ArrayBuffer) -> (), ptr is passed in "mapped" state.
    // return: GpuBuffer (no longer mapped, directly usable)
    createUniformBuffer(size, initFn) {
        const buf = this.device.createBuffer({
            size: size,
            usage: GPUBufferUsage.UNIFORM | GPUBufferUsage.COPY_DST,
            mappedAtCreation: true,
        });
        initFn(buf.getMappedRange(0, size));
        buf.unmap();
        return buf;
    }

    // Create buffer for reading to cpu.
    // Supports: bulk-copy from other buffer, bulk read from cpu.
    // Does not support: shader read/write
    createBufferForCpuRead(size) {
        return this.device.createBuffer({
            size: size,
            usage: GPUBufferUsage.MAP_READ | GPUBufferUsage.COPY_DST,
        });
    }

    // Create a single pipeline.
    // [in] entryPoint: string, entry point name
    // [in] bindings: array of string, "storage" | "uniform"
    // [in] shaderCode: string, WGSL code
    #createPipeline(entryPoint, bindings, shaderCode) {
        const shaderModule = this.device.createShaderModule({ code: shaderCode });

        const bindGroupLayout = this.device.createBindGroupLayout({
            entries: bindings.map((type, i) => ({
                binding: i,
                visibility: GPUShaderStage.COMPUTE,
                buffer: { type }
            })),
        });

        return this.device.createComputePipeline({
            layout: this.device.createPipelineLayout({bindGroupLayouts: [bindGroupLayout]}),
            compute: { module: shaderModule, entryPoint }
        });
    }

    // Dispatch kernel.
    // [in] commandEncoder: GPUCommandEncoder
    // [in] pipeline: GPUComputePipeline
    // [in] args: array of GPUBuffer. Will be assigned to binding 0, 1, 2, ... automatically.
    // [in] numThreads: number of total threads (wanted kernel execs)
    #dispatchKernel(commandEncoder, pipeline, args, numThreads) {
        const bindGroup = this.device.createBindGroup({
            layout: pipeline.getBindGroupLayout(0),
            entries: args.map((buf, i) => ({ binding: i, resource: { buffer: buf } }))
        });

        const passEncoder = commandEncoder.beginComputePass();
        passEncoder.setPipeline(pipeline);
        passEncoder.setBindGroup(0, bindGroup);
        passEncoder.dispatchWorkgroups(Math.ceil(numThreads / 128));
        passEncoder.end();
    }

    #compileRadixPadding() {
        this.padForRadixSortPipeline = this.#createPipeline("pad_for_radix_sort", ["storage"], `
                @group(0) @binding(0) var<storage, read_write> arr_out: array<u32>;

                @compute @workgroup_size(128)
                fn pad_for_radix_sort(@builtin(global_invocation_id) gid: vec3<u32>) {
                    let ix = gid.x;
                    if (ix >= arrayLength(&arr_out)) {
                        return;
                    }
                    arr_out[ix] = 0xffffffff;
                }
            `
        );
    }

    // Gets (or rebuild) Radix sort kernel and usable buffers.
    // Returned buffers are guaranteed to be large enough to hold count elements.
    // Caller MUST NOT use 0xffffffff as keys, as they're internally used as padding.
    // Caller MUST copy the result to other buffers before calling this method again.
    //
    // Kernel recompiles iff count is bigger than previous ones.
    //
    // [in] count: number, number of elements
    // returns {keysBuf (u32 buf), valuesBuf (u32 buf), kernel: RadixSortKernel}
    #prepareCachedRadixSortKernel(count, commandEncoder) {
        if (!this.cachedRadixSortSize || this.cachedRadixSortSize < count) {
            // rebuild
            const keysBuf = this.createBuffer(count * 4);
            const valuesBuf = this.createBuffer(count * 4);
            const kernel = new RadixSortKernel({
                device: this.device,
                keys: keysBuf,
                values: valuesBuf,
                count: count,
            });
            this.cachedRadixSortSize = count;
            this.cachedRadixSort = { keysBuf, valuesBuf, kernel };
        }

        // Pad key buffer. (So that these unused elements will go to the end of the array)
        this.#dispatchKernel(commandEncoder, this.padForRadixSortPipeline, [this.cachedRadixSort.keysBuf], this.cachedRadixSortSize);
        
        return this.cachedRadixSort;
    }

    async debugPrintBuffer(mark, buf) {
        const SIZE_LIMIT = 128;
        const size = Math.min(buf.size, SIZE_LIMIT);

        let usage = buf.usage;
        const usageStrs = [];
        const usageFlags = [
            [GPUBufferUsage.MAP_READ, "MAP_READ"],
            [GPUBufferUsage.MAP_WRITE, "MAP_WRITE"], 
            [GPUBufferUsage.COPY_DST, "COPY_DST"],
            [GPUBufferUsage.COPY_SRC, "COPY_SRC"],
            [GPUBufferUsage.UNIFORM, "UNIFORM"],
            [GPUBufferUsage.STORAGE, "STORAGE"]
        ];
        for (const [flag, name] of usageFlags) {
            if (usage & flag) {
                usageStrs.push(name);
                usage &= ~flag;
            }
        }
        if (usage) {
            usageStrs.push(`${usage.toString(16)}`);
        }

        // Somehow copy to cpu buffer
        const dumpString = `${mark}:Buffer label=${buf.label} size=${buf.size} usage=${usageStrs.join("|")} map=${buf.mapState}`;
        if (buf.usage & GPUBufferUsage.COPY_SRC) {
            // copiable
            const debugBuffer = this.createBufferForCpuRead(size);
            await this.device.queue.onSubmittedWorkDone();
            
            const commandEncoder = this.device.createCommandEncoder();
            commandEncoder.copyBufferToBuffer(buf, 0, debugBuffer, 0, size);
            this.device.queue.submit([commandEncoder.finish()]);
            await this.device.queue.onSubmittedWorkDone();
            await debugBuffer.mapAsync(GPUMapMode.READ);
            const cpuDebugBuffer = debugBuffer.getMappedRange(0, size).slice(); // NOTE: "slice" copies data
            debugBuffer.unmap();

            console.log(dumpString);
            console.log(`${mark}:Buffer/First ${size}B as f32`, new Float32Array(cpuDebugBuffer));
            console.log(`${mark}:Buffer/First ${size}B as u8`, new Uint8Array(cpuDebugBuffer));
        } else {
            console.log(dumpString);
            console.log(`${mark}:Buffer/Not copiable`);
        }
    }

    async _readAllV4(buf) {
        const numVecs = buf.size / 16;
        const tempBuffer = this.createBufferForCpuRead(numVecs * 16);
        await this.device.queue.onSubmittedWorkDone();
        
        const commandEncoder = this.device.createCommandEncoder();
        commandEncoder.copyBufferToBuffer(buf, 0, tempBuffer, 0, numVecs * 16);
        this.device.queue.submit([commandEncoder.finish()]);
        await this.device.queue.onSubmittedWorkDone();

        await tempBuffer.mapAsync(GPUMapMode.READ);
        const view = new Float32Array(tempBuffer.getMappedRange(0, numVecs * 16));
        const pts = [];
        for (let i = 0; i < numVecs; i++) {
            pts.push(new THREE.Vector4(
                view[i * 4 + 0],
                view[i * 4 + 1],
                view[i * 4 + 2],
                view[i * 4 + 3]
            ));
        }
        tempBuffer.unmap();
        return pts;
    }

    #compileInit() {
        this.initPipeline = this.#createPipeline("init", ["storage", "uniform"], `
                @group(0) @binding(0) var<storage, read_write> points: array<vec4f>;
                
                struct Params {
                    size: vec4f, // xyz: min point coordinates, w: step
                    dims: vec4u, // xyz: number of points in each axis, w: unused
                }
                @group(0) @binding(1) var<uniform> params: Params;

                fn rand1D(i: f32) -> f32 {
                    return fract(sin(i * 12.9898) * 43758.5453);
                }

                fn xs32(s: u32) -> u32 { var x=s; x^=x<<13; x^=x>>17; x^=x<<5; return x; }
                fn rand01(cnt: u32, key: u32) -> f32 {
                    return f32(xs32(cnt * key)) * (1.0 / 4294967296.0);
                }

                @compute @workgroup_size(128)
                fn init(@builtin(global_invocation_id) id: vec3u) {
                    let index = id.x;
                    if(index >= arrayLength(&points)) {
                        return;
                    }
                    
                    let z = index / (params.dims.x * params.dims.y);
                    let y = (index % (params.dims.x * params.dims.y)) / params.dims.x;
                    let x = index % params.dims.x;

                    let noise = vec3f(
                        rand01(u32(index), 0xca272690),
                        rand01(u32(index), 0xb8100b94),
                        rand01(u32(index), 0x13941583)) * 0.5;

                    let pos_local = 
                        params.size.xyz +
                        (vec3f(f32(x), f32(y), f32(z)) + noise) * params.size.w;
                    points[index] = vec4f(pos_local, 1);
                }
            `
        );
    }

    // Initialize point cloud.
    // [in] size: THREE.Vector3
    // [in] pointsPerMm: number
    // returns: buffer (vec4)
    async initBox(size, pointsPerMm) {
        const pointsPerAxis = size.clone().multiplyScalar(pointsPerMm).ceil();
        const numPoints = pointsPerAxis.x * pointsPerAxis.y * pointsPerAxis.z;
        const minPoint = size.clone().multiplyScalar(-0.5);

        const pointsBuf = this.createBuffer(numPoints * 16);
        const paramBuf = this.createUniformBuffer(32, (ptr) => {
            new Float32Array(ptr, 0, 4).set([
                minPoint.x, minPoint.y, minPoint.z, 1 / pointsPerMm,
            ]);
            new Uint32Array(ptr, 16, 4).set([
                pointsPerAxis.x, pointsPerAxis.y, pointsPerAxis.z, 0,
            ]);
        });

        const commandEncoder = this.device.createCommandEncoder();
        this.#dispatchKernel(commandEncoder, this.initPipeline, [pointsBuf, paramBuf], numPoints);
        this.device.queue.submit([commandEncoder.finish()]);
        await this.device.queue.onSubmittedWorkDone();

        paramBuf.destroy();

        return pointsBuf;
    }

    #compileApplyCylinder() {
        this.applyCylinderPipeline = this.#createPipeline("apply_cylinder", ["storage", "storage", "uniform"], `
                @group(0) @binding(0) var<storage, read_write> ps_in: array<vec4f>;
                @group(0) @binding(1) var<storage, read_write> ps_out: array<vec4f>;
                @group(0) @binding(2) var<uniform> diameter: f32;

                @compute @workgroup_size(128)
                fn apply_cylinder(@builtin(global_invocation_id) gid: vec3u) {
                    let index = gid.x;
                    if (index >= arrayLength(&ps_in)) {
                        return;
                    }

                    let p = ps_in[index];
                    let p_radius = length(p.xy);
                    ps_out[index] = vec4(p.xyz, select(0.0, 1.0, p_radius <= diameter * 0.5 && p.w > 0.5));
                }
            `
        );
    }
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
                void main() {
                    float radius = length(gl_PointCoord - 0.5);
                    if (radius > 0.5) {
                        discard;
                        return;
                    }
                    if (vert_col.w < 0.5) {
                        discard;
                        return;
                    }

                    gl_FragColor = vec4(vert_col.rgb, 1.0);
                }
            `,
        });

        const pointsMaterialW = pointsMaterialPrototype.clone();
        pointsMaterialW.uniforms.key_color.value = new THREE.Color(0.7, 0.7, 1.0);
        const pointsMaterialT = pointsMaterialPrototype.clone();
        pointsMaterialT.uniforms.key_color.value = new THREE.Color(1.0, 0.7, 0.7);

        // Create points geometry for each solid
        this.solidWPoints = new THREE.Points(
            new THREE.BufferGeometry(),
            pointsMaterialW
        );
        this.solidTPoints = new THREE.Points(
            new THREE.BufferGeometry(),
            pointsMaterialT
        );
        // Disable frustum culling, as they have problems when camera is extremely close.
        this.solidWPoints.frustumCulled = false;
        this.solidTPoints.frustumCulled = false;

        this.scene.add(this.solidWPoints);
        this.scene.add(this.solidTPoints);

        // Prepare tool path visualization
        this.toolPathMarkersPosList = [
            new THREE.Vector3(1.5 / 2, 0, -5),
            new THREE.Vector3(0, 0, -5),
            new THREE.Vector3(-1.5 / 2, 0, -5),
        ];
        this.updateToolPathVis();
    }

    setupGui() {
        const gui = new GUI();

        gui.add(this, "toolShape", ["cylinder", "square"]).name("Tool Shape").onChange(async () => {
            await this.#regenerateTool();
            this.flagPointsForUpdate();
        });

        const pathModeUpdated = () => {
            switch (this.pathMode) {
                case "linear":
                    feedDirGui.show();
                    helixDiaGui.hide();
                    helixPitchGui.hide();
                    break;
                case "helical":
                    feedDirGui.hide();
                    helixDiaGui.show();
                    helixPitchGui.show();
                    break;
            }
        };

        const toolPathUpdated = () => {
            this.simulator.transT = this.computeToolTrans(0);
            this.updateToolPathVis();
            this.flagPointsForUpdate();
        };
        
        gui.add(this, "toolInitX", -15, 15, 0.1).name("Tool Init X (mm)").onChange(toolPathUpdated);
        gui.add(this, "toolInitY", -15, 15, 0.1).name("Tool Init Y (mm)").onChange(toolPathUpdated);
        gui.add(this, "toolInitZ", -5, 5, 0.1).name("Tool Init Z (mm)").onChange(toolPathUpdated);

        gui.add(this, "pathMode", ["linear", "helical"]).name("Path Mode").onChange(_ => {
            pathModeUpdated();
            toolPathUpdated();
        });

        const feedDirGui = gui.add(this, "feedDir", 0, 90, 1).name("Feed Dir (deg)").onChange(toolPathUpdated);
        const helixDiaGui = gui.add(this, "helixDiameter", 0, 20, 0.1).name("Helix Dia. (mm)").onChange(toolPathUpdated);
        const helixPitchGui = gui.add(this, "helixPitch", 0.1, 5, 0.1).name("Helix Pitch (mm)").onChange(toolPathUpdated);
        pathModeUpdated();

        gui.add(this, "feedDist", 0, 50, 1).name("Feed Dist (mm)").onChange(toolPathUpdated);

        gui.add(this, "toolRot", 0, 360, 1).name("Tool Rot (deg/mm)").onChange(toolPathUpdated);
        gui.add(this, "ewr", 0, 500, 1).name("E. Wear Ratio (%)");

        gui.add(this, "run");
        gui.add(this, "stop");
        gui.add(this, "reset");
        gui.add(this, "currentSimFeedDist").name("Current Feed (mm)").disable().listen();

        gui.add(this, "slice").name("Slice (YZ)").onChange(() => {
            this.solidWPoints.material.uniforms.use_slice.value = this.slice ? 1 : 0;
            this.solidTPoints.material.uniforms.use_slice.value = this.slice ? 1 : 0;
        });
        gui.add(this, "sliceX", -15, 15, 0.1).name("Slice Pos (mm)").onChange(() => {
            this.solidWPoints.material.uniforms.slice_x.value = this.sliceX;
            this.solidTPoints.material.uniforms.slice_x.value = this.sliceX;
        });
    }

    computeToolTrans(feedDist) {
        const pos = new THREE.Vector3(this.toolInitX, this.toolInitY, 5 + this.toolInitZ);
        const rot = new THREE.Quaternion().setFromAxisAngle(new THREE.Vector3(0, 0, 1), feedDist * this.toolRot * Math.PI / 180);

        if (this.pathMode == "linear") {
            const angle = this.feedDir * Math.PI / 180;
            pos.add(new THREE.Vector3(feedDist * Math.sin(angle), 0, -feedDist * Math.cos(angle)));
        } else if (this.pathMode == "helical") {
            const singleRotFeedDist = Math.hypot(this.helixDiameter * Math.PI, this.helixPitch);
            const helixRot = feedDist / singleRotFeedDist;
            const helixAngle = -helixRot * 2 * Math.PI;
            pos.add(new THREE.Vector3(this.helixDiameter * 0.5 * Math.cos(helixAngle), this.helixDiameter * 0.5 * Math.sin(helixAngle), -this.helixPitch * helixRot));
        }
        return makeTrans(pos, rot);
    }

    updateToolPathVis() {
        const computeToolTrans = (t) => this.computeToolTrans(t * this.feedDist);
        class ToolPathCurve extends THREE.Curve {
            constructor(init) {
                super();
                this.init = init;
            }
            getPoint(t, optionalTarget = new THREE.Vector3()) {
                return optionalTarget.copy(this.init).applyMatrix4(computeToolTrans(t));
            }
        }
        const vis = new THREE.Object3D();
        this.toolPathMarkersPosList.forEach(init => {
            const path = new THREE.Mesh(
                new THREE.TubeGeometry(new ToolPathCurve(init), 1024, 0.03, 6),
                new THREE.MeshBasicMaterial({color: "darkgray"}));
            vis.add(path);
        });
        
        if (this.toolPathVis) {
            this.scene.remove(this.toolPathVis);
        }
        this.scene.add(vis);
        this.toolPathVis = vis;
        return vis;
    }

    run() {
        this.stopSimulation = false;

        // ewr = 0%: ratio = 0
        // ewr = 100%: ratio = 0.5
        const ewr = this.ewr / 100;
        const ratio = ewr / (1 + ewr);

        const simulateAsync = async () => {
            console.log("simulation start");
            const t0 = performance.now();
            this.currentSimFeedDist = 0;
            while (this.currentSimFeedDist <= this.feedDist) {
                this.simulator.transT = this.computeToolTrans(this.currentSimFeedDist);

                const t0 = performance.now();
                await simulator.removeClose(1 / POINTS_PER_MM, ratio);
                const t1 = performance.now();
                console.log("GPU-removeClose", t1 - t0, "ms");

                this.flagPointsForUpdate();

                if (this.stopSimulation) {
                    break;
                }

                this.currentSimFeedDist += 0.5 / POINTS_PER_MM; // TODO: this won't work if tool is rotating super fast
            }
            const t1 = performance.now();
            console.log(`Simulate: ${t1 - t0} ms`);
        };

        simulateAsync(); // fire and forget
    }

    stop() {
        this.stopSimulation = true;
    }

    reset() {
        this.stopSimulation = true;
        this.currentSimFeedDist = 0;

        const regen = async () => {
            this.simulator.transT = this.computeToolTrans(0);
            await this.#regenerateTool();
            await this.#regenerateWork();
            this.flagPointsForUpdate();
        };
        regen(); // fire and forget
    }

    async #regenerateTool() {
        this.simulator.solidT = await this.simulator.kernels.initBox(this.simulator.shapeT.sizeLocal, POINTS_PER_MM);
        if (this.toolShape == "cylinder") {
            this.simulator.solidT = await this.simulator.kernels.applyCylinder(this.simulator.solidT, 1.5);
        }
    }

    async #regenerateWork() {
        this.simulator.solidW = await this.simulator.kernels.initBox(this.simulator.shapeW.sizeLocal, POINTS_PER_MM);
    }

    onWindowResize() {
        const width = window.innerWidth;
        const height = window.innerHeight;

        this.camera.aspect = width / height;
        this.camera.updateProjectionMatrix();

        this.renderer.setSize(width, height);
    }

    flagPointsForUpdate() {
        this.requestFrame = this.currentFrame;
    }
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

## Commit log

2024-08-11 Init (STL 2D slicing)
    [Dice Tower.stl, helical_gear.stl]
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2024-08-12 Hide vis replacement logic behind View3D
    [main.js]
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2024-08-12 Adjust resolutions to fit plausible physics & add benchy & bolt
    [M3x10.stl, benchy_25p.stl, dice_tower.stl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]
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2024-08-31 Decrease max current to 1.7A to prevent diode breakage
    [test.kicad_sch]
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2024-09-21 Implement simulated annealing & fix stability
    [main.js]
2024-10-08 Add CTRL-MINI w/ TMC2130 driver boards
    [CTRL-MINI-MD.kicad_pcb, CTRL-MINI-MD.kicad_sch, CTRL-MINI.kicad_pcb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]
2024-10-08 Optimize RPP pin assignment and reserve UART0 & SPI1
    [CTRL-MINI.kicad_sch]
2024-10-09 Use jumper to switch 0.4A / 0.2A
    [CTRL-MINI-MD.kicad_sch]
2024-10-11 CTRL-MINI-ED all params are fixed for the first time
    [CTRL-MINI-ED.kicad_pcb, CTRL-MINI-ED.kicad_sch]
2024-10-14 DRC-pass in MD board as 4-layer PCB
    [CTRL-MINI-MD.kicad_pcb, CTRL-MINI-MD.kicad_sch]
2024-10-14 CTRL-MINI PCB r0 passed DRC as 2-layer
    [CTRL-MINI.kicad_pcb, CTRL-MINI.kicad_sch]
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2024-10-14 Replace zener with more available 5.1V & SOD523 package
    [CTRL-MINI-ED.kicad_pcb, CTRL-MINI-ED.kicad_sch]
2024-10-15 Polish contact detection circuit by simulation
    [CTRL-MINI-ED-sim-sense.kicad_sch]
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2024-10-15 Update ED (current sensor, output protection diode) based on sims
    [CTRL-MINI-ED-sim-dchg.kicad_sch, CTRL-MINI-ED.kicad_sch]
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2024-10-15 Change CTRl-MINI MB size to metric
    [CTRL-MINI.kicad_pcb]
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2024-10-16 Increase silkscreen width & avoid via-silk collision
    [CTRL-MINI.kicad_pcb]
2024-10-16 Improve manufacturability of MB, use SOD-523
    [CTRL-MINI.kicad_pcb, CTRL-MINI.kicad_sch]
2024-10-16 Fix out-of-board silks
    [CTRL-MINI.kicad_pcb]
2024-10-25 Remove testpads from BOM
    [CTRL-MINI-ED.kicad_pcb, CTRL-MINI-ED.kicad_sch]
2024-10-25 Change analog switch to be better and more available one, add LCSC annots
    [CTRL-MINI-ED.kicad_pcb, CTRL-MINI-ED.kicad_sch]
2024-10-25 Improve diode & fuse availability
    [CTRL-MINI-ED.kicad_pcb, CTRL-MINI-ED.kicad_sch]
2024-10-25 Use more common N-ch MOSFET pattern
    [CTRL-MINI-ED.kicad_pcb, CTRL-MINI-ED.kicad_sch]
2024-10-25 Fix DFM errors
    [CTRL-MINI-MD.kicad_pcb]
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2024-11-09 Fix MD SPI & GPIO configs
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2024-11-10 Tune StallGuard parameters
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2024-11-26 Shorten wait in case of timeout
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2024-11-30 Fix pump counter
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2024-12-11 CTRL-MINI-ED r1 draft schematics
    [AD-MSOP-LT8365.step, CTRL-MINI-ED-sim-dchg.kicad_sch, CTRL-MINI-ED-sim-sense.kicad_sch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]
2024-12-11 Add PWM voltage divider and refactor
    [CTRL-MINI-ED-sim-sense.kicad_sch, CTRL-MINI-ED.kicad_pcb, CTRL-MINI-ED.kicad_sch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]
2024-12-11 Fix revision number
    [CTRL-MINI-ED.kicad_sch, boost_converter_100v.kicad_sch, gate_pwm_filter.kicad_sch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]
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2024-12-12 Draft of PCB layout
    [CTRL-MINI-ED.kicad_pcb, CTRL-MINI-ED.kicad_sch, gate_pwm_filter.kicad_sch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]
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2024-12-13 Basic building block layout
    [CTRL-MINI-ED.kicad_pcb, CTRL-MINI-ED.kicad_sch, boost_converter_100v.kicad_sch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]
2024-12-13 All wired and DRC passed
    [CTRL-MINI-ED.kicad_pcb]
2024-12-14 Bunch of transfer & stich vias. Tweaks to pass DRC
    [CTRL-MINI-ED.kicad_pcb]
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2024-12-15 Increase min via size to 0.3 hole/0.6mm dia for manufacturability
    [CTRL-MINI-ED.kicad_pcb]
2024-12-15 Fix wrong part & footprint assignment
    [CTRL-MINI-ED.kicad_pcb, boost_converter_100v.kicad_sch, gate_pwm_filter.kicad_sch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]
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2025-01-02 Adjust orientation to WG-1, fix bug at coarse grid dicing
    [GT2_pulley.stl]
2025-01-02 Add reset + Z pos
    [main.js]
2025-01-07 Fix work rotation handling
    [main.js]
2025-01-14 Replace dilation by sdf offsetting
    [main.js]
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2025-01-16 Improve GPU stability by avoiding duplicated update & early-destroy
    [main.js]
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2025-01-17 Replace model, impl diameter change
    [cube_lattice.stl, dice_tower.stl]
2025-01-20 Fix part off diameter
    [main.js]
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2025-01-28 Update ED test instruction & LED error blink
2025-01-28 Rename pcb & firmware to be more meaningful
    [CORE.kicad_pcb, CORE.kicad_sch, CTRL-MINI-ED-sim-sense.kicad_sch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]
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2025-02-03 Replace sweep-visy w/ .vlog
    [main.js]
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2025-02-09 Apply strict warning and fix thresh pwm bug
2025-02-10 1us window GATE noise filtering
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2025-02-13 Add bode plot analysis of opamp-mosfet-load-rsense loop
    [PULSER-sim-control.kicad_sch]
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2025-02-24 PULSER r2 pulse shaper draft
    [PULSER-sim-dchg.kicad_sch, PULSER.kicad_pcb, PULSER.kicad_sch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]
2025-02-25 PULSER r2 schematics ok
    [Omron_Relay_DPDT2C_G2R.step, PULSER-sim-control.kicad_sch, PULSER.kicad_pcb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]
2025-02-26 PULSER r2 PCB draft
    [PG-TDSON-8.step, PULSER.kicad_pcb, PULSER.kicad_sch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]
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2025-02-27 Fix caps, improve schematic docs
    [PULSER.kicad_sch, boost_converter_100v.kicad_sch, mux_half_bridge.kicad_sch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]
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2025-02-27 Stich GND by vias
    [PULSER.kicad_pcb]
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2025-02-28 Fix FCC conn orientation, fix diode DFM issues
    [PULSER.kicad_pcb, bom.csv, positions.csv]
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2025-03-06 Fix I2C type error
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2025-03-09 Find issue was due to hardware failure. Revert current change
2025-03-11 PCB mocks & foot
    [CORE-R0.step, PULSER-R2.step, inlet-15CBE1.step]
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2025-03-17 Add DIN clips for PCB
    [din_clip_core.stl, din_clip_pulser.stl, frame_joint.stl]
2025-03-18 Fix temp sensor I2C & current offset
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2025-03-21 Fix current conversion
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2025-03-27 PULSER r3 schematics draft
    [PULSER.kicad_pcb, PULSER.kicad_sch, boost_converter_100v.kicad_sch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]
2025-03-27 PULSER r3 PCB DRC pass
    [PULSER.kicad_pcb, PULSER.kicad_sch, boost_converter_100v.kicad_sch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]
2025-03-27 PULSER r3 JLCPCB files
    [PULSER.kicad_pcb, bom.csv, designators.csv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]
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2025-04-14 Fix 0 hole DIN clip
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2025-05-22 refactor: Update grblHAL error logging based on feedback
    This commit incorporates your feedback to refine the grblHAL
    error logging feature:
    - Error messages for codes 18 ("Reset asserted") and 19
    ("Non positive value") are now correctly populated in
    `shell-spooler/grbl_errors.go`.
    - Logging in `shell-spooler/grblhal.go` is simplified. A
    human-readable message is logged with `slog.Info` only if
    the error code is successfully parsed, found in the map,
    and the message string is not empty. No special logging
    occurs otherwise.
    - The internal variable for the error message string has been
    renamed from `humanReadableMessage` to `errorText` for brevity.
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2025-05-23 Refactor spooler & display command error in UI
    [main.js]
2025-06-08 Simplify structure by moving pulser & corefw to other repos
    [AD-MSOP-LT8365.step, Bourns_Fuse_SF_6.1x2.6.step, CORE.kicad_pcb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]
2025-06-21 Fix all type (and some missing variable) errors
    [main.js]
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2025-07-19 Fix wirefeed polarity
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2025-09-06 dashboard: always energize Y-axis motor to prevent slips
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2025-09-20 spooler: fix flow control (conc error, proper delay)
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2025-09-20 dashboard: fix pos printing
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2025-09-30 sim-m: fix initial camera error
2025-09-30 dicer: better camera angle and resize bugfix
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2025-10-01 dicer: tighten meaning of getnPath
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2026-06-08 dicer: Add new "thickness" sample model
    [thickness.stl]
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2026-06-12 Add new "flush_end" sample
    [flush_end.stl]
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2026-08-26 Pump & DC converter mounts
    [base-assy.FCStd, bracket-pump.FCStd, converter-assy.FCStd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]
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2026-08-27 Move bearing to vitamins
    [assy-z.FCStd, mm-x-assy.FCStd, mock-F684ZZ.FCStd]
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2026-08-27 Use beltdrive modules for XYZ
    [assy-z.FCStd, beltdrive-assy.FCStd, mm-assy.FCStd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]
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2026-08-31 bearing bracket for y-assy
    [bracket-bearing.FCStd, mm-y-assy.FCStd, work-spindle-assy.FCStd]
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2026-09-08 Working chuck (without electrode)
    [chuck-assy.FCStd, chuck-base.FCStd, chuck-retainer.FCStd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]
2026-09-08 Prototype of tool water sprinkler
    [sprinkler-rod.FCStd]
2026-09-08 Prototype of rotary wire carrier for work spindle
    [rotary-wire-carrier.FCStd]
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2026-09-10 C axis pressured bearing assy
    [assy-scissor.FCStd, assy-z.FCStd, mock-collar.FCStd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]
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2026-09-10 Fix plate-z overall size
    [assy-scissor.FCStd, assy-z.FCStd, bracket-bearing.FCStd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]
2026-09-10 betldrive ext if draft, adjust mm
    [assy-scissor.FCStd, assy-z.FCStd, base-beltdrive.FCStd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]
2026-09-10 mount pt for beltdrive
    [base-beltdrive.FCStd, belt-clip.FCStd, beltdrive-assy.FCStd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]
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2026-09-16 Add parametric interface/mock for beltdrive
    [if-beltdrive.FCStd]
2026-09-16 Make mm-x to use if-beltdrive
    [assy-scissor.FCStd, assy-z.FCStd, if-beltdrive.FCStd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]
2026-09-16 Adjust plate-z, use misumi SSE8
    [assy-scissor.FCStd, assy-z.FCStd, mm-x-assy.FCStd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]
2026-09-16 Use smaller z collar for assy clearance
    [assy-scissor.FCStd, assy-z.FCStd, mock-collar.FCStd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]
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2026-09-16 Fix error in scissor
    [assy-scissor.FCStd, scissor.FCStd]
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2026-09-16 Use SSE10 for X
    [assy-z.FCStd, mm-x-assy.FCStd, mock-SSE10-block.FCStd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]
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2026-09-17 Fix y strokes
    [bracket-mm.FCStd, cover-bot.FCStd, mm-assy.FCStd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]
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2026-09-28 Fix z coupler nut pos bug
    [z-coupler-2.FCStd]
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2026-10-01 Fix missing parametrization
    [if-beltdrive.FCStd]
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
